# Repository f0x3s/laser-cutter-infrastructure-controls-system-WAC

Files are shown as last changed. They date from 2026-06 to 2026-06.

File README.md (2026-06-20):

# Laser Cutter Infrastructure Controls System
Relay-logic-based controls system to manage water-cooling, fume ventilation, and other auxiliary functions for the laser cutter &amp; digital fabrication space at the Walker Art Center.

This is intended as a maintenance resource for the existing system. Instructions for building a new system from scratch are currently outside of the scope of this repo.

> ### Additional Resources:
> * [arduino-industrial-AHU-status-indicator-WAC](https://github.com/f0x3s/arduino-industrial-AHU-status-indicator-WAC) — *Real-time feedback module for the __Paint Booth AHU__*
> * [arduino-industrial-AHU-interface-WAC](https://github.com/f0x3s/arduino-industrial-AHU-interface-WAC) — *Interface beween control module and __Paint Booth AHU__ 3-phase motor controller*

## Control Flow
<p align="center">
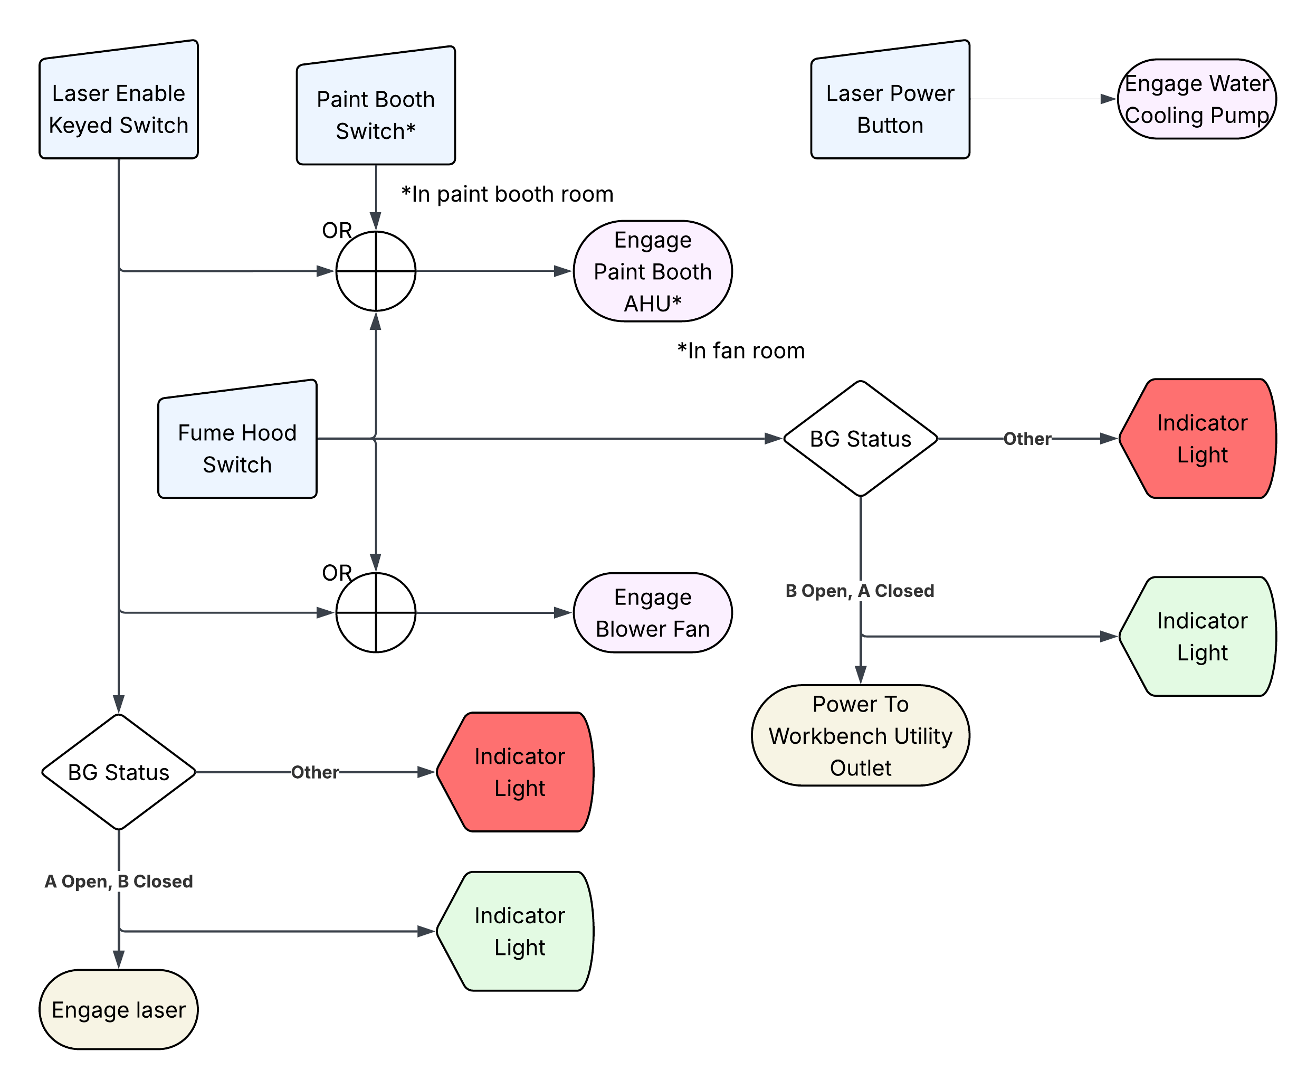
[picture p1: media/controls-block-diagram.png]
control flow block diagram
    
</p>

### Overview:
* **Water Cooling Pump** controlled with **Laser Power Button**, ensuring **Water Cooling Pump** is always engaged during **Laser** operation. 
* The **Paint Booth Air Handling Unit (AHU)** and local **Blower Fan** ensured to be always on while **Laser** or **Fume Hood** in use.
* Power to both a **Utility Outlet** at the fume hood workbench (to restrict access to fume-generating tools, like a soldering iron) and internal **Laser Tube** will be interrupted until correct orientation of **Blast Gates** is met, with **Indicator Lights** providing visual feedback.
* While not explicitly shown in this diagram, during operation of either the **Laser** or **Fume Hood** the switch in the **Paint Booth** is interrupted at the **Paint Booth AHU** motor controller in the **Fan Room** so that it may not be used to turn off **Paint Booth AHU**. See: ['arduino-industrial-AHU-interface-WAC'](https://github.com/f0x3s/arduino-industrial-AHU-interface-WAC)

## Air Handling Diagram
<p align="center">
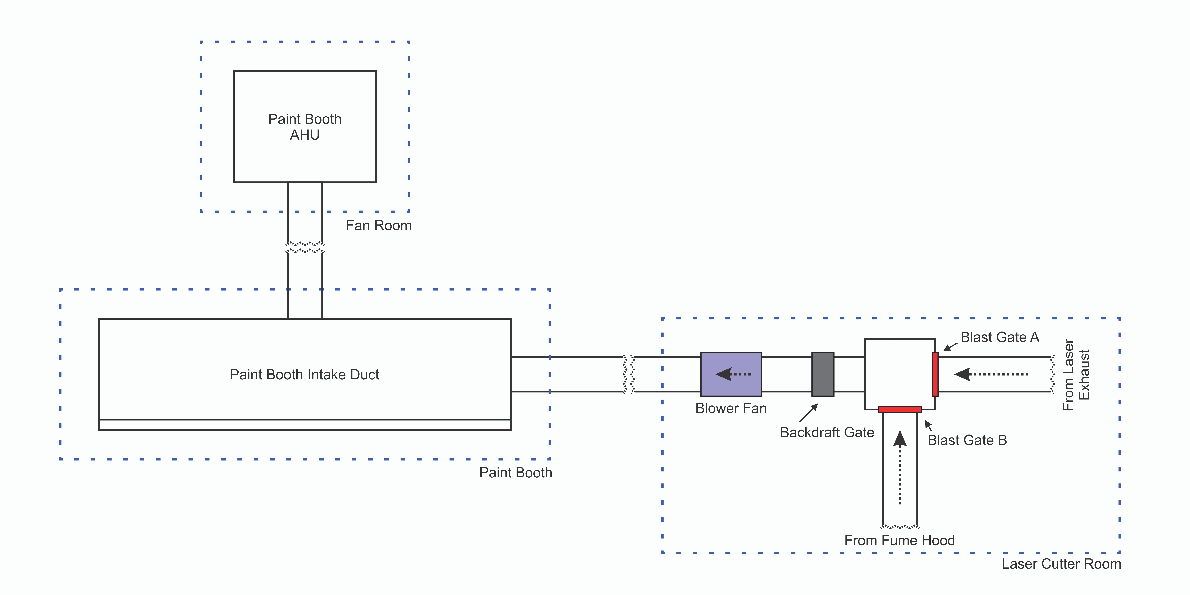
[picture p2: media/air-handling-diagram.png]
air handling diagram
    
</p>

#### Air Handling Specialty Parts
| qty | name | source |
| ---: | :---: | :---: |
| 2 | Long Ranger 4 in. Aluminum Blast Gate with Switch | [Penn State Industries](https://www.pennstateind.com/store/LRGATE.html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) |
| 1 | 6" Backdraft Damper | [Amazon](https://a.co/d/00BVJb6u) |

## Circuit Diagrams
#### Main Control Module
<p align="center">
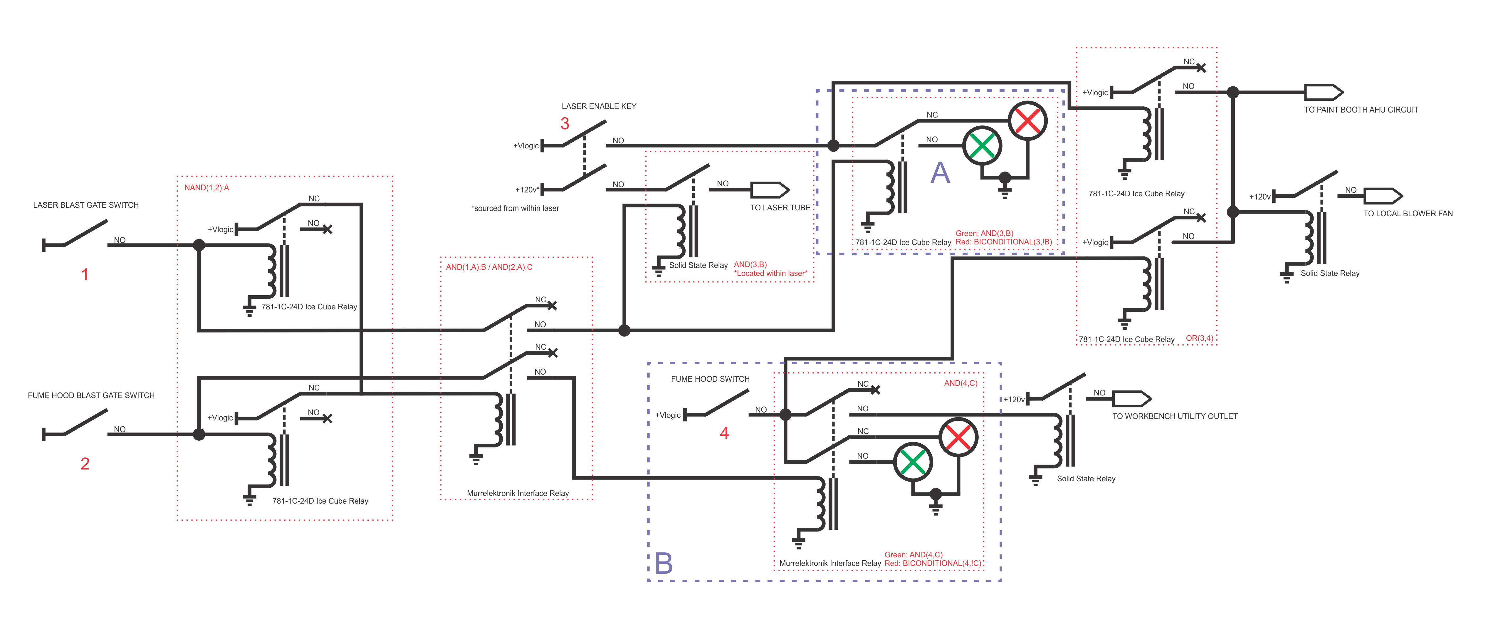
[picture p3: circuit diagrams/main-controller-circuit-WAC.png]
main control module electrical schematic
    
</p>

#### Indicator Light Modules
<p align="center">
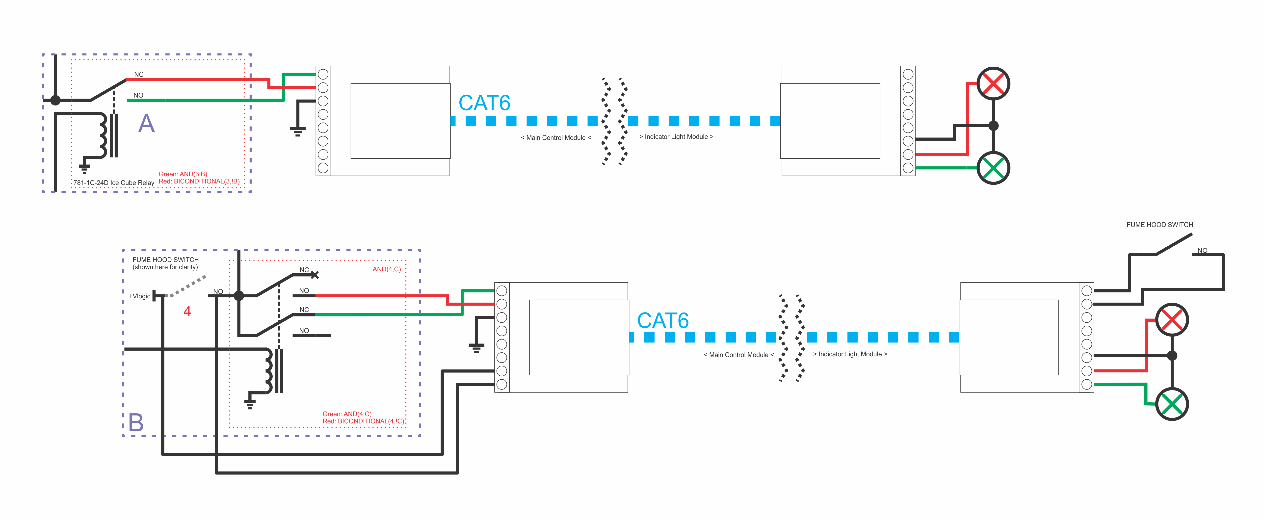
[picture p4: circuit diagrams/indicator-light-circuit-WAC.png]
indicator modules electrical schematic
    
</p>

#### Water Cooler Control Module
<p align="left">
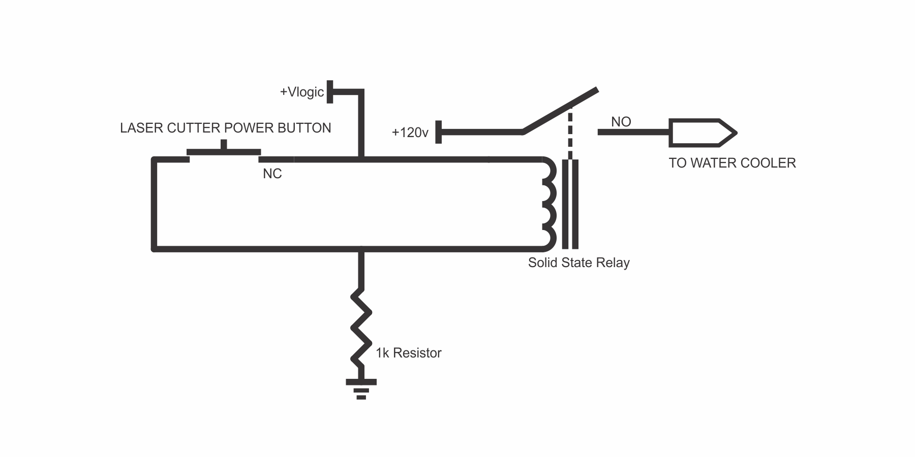
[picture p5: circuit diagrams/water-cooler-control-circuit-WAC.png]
water cooler control module electrical schematic
    
</p>

## Fabrication Files
All files to be cut from 0.25" acrylic unless otherwise specified.
> 📂 **[acrylic parts](acrylic%20parts)/**
> - 📁 [`source`](acrylic%20parts/source)/ — *Editable Corel Draw design files*
>   - 🗒️ [`indicator-light-enclosure-WAC.cdr`](acrylic%20parts/source/indicator-light-enclosure-WAC.cdr)
>   - 🗒️ [`relay-controller-main-enclosure-WAC.cdr`](acrylic%20parts/source/relay-controller-main-enclosure-WAC.cdr)
>   - 🗒️ [`relay-controller-water-cooler-enclosure.cdr`](acrylic%20parts/source/relay-controller-main-enclosure-WAC.cdr)
> - 🗒️ [`indicator-light-enclosure-WAC.dxf`](acrylic%20parts/indicator-light-enclosure-WAC.dxf) — *Enclosure for red/green blast gate status indicator lights*
> - 🗒️ [`relay-controller-main-enclosure-WAC.dxf`](acrylic%20parts/relay-controller-main-enclosure-WAC.dxf) — *Enclosure for primary relay logic module*
> - 🗒️ [`relay-controller-water-cooler-enclosure-WAC.dxf`](acrylic%20parts/relay-controller-water-cooler-enclosure-WAC.dxf) — *Enclosure for water cooler activation relay*

## Control Modules Parts Lists
_note: qty given as needed for assembly, without respect to package quantity from sources_
#### Indicator Light Module (per module)
_Requires 1x [`indicator-light-enclosure-WAC.dxf`](acrylic%20parts/indicator-light-enclosure-WAC.dxf)_
| qty | name | source |
| ---: | :---: | :---: |
| 10 | M3 nuts | [McMaster](https://www.mcmaster.com/90710A030/) |
| 8 | M3 x 16mm Button Head Machine Screw | [McMaster](https://www.mcmaster.com/92095A184/) |
| 2 | M3 x 35mm Button Head Machine Screw | [McMaster](https://www.mcmaster.com/92095A201/) |
| 2 | Nylon Standoff | [McMaster](https://www.mcmaster.com/90176A166/) |
| 2 |  3/16 x 1-3/4 concrete screw | [McMaster](https://www.mcmaster.com/90161A725/) |
| 1 |  RJ45 Socket Breakout | [Amazon](https://a.co/d/0dmWGGhN) |
| 1 |  Red & Green Indicator Light Pair | [Amazon](https://a.co/d/08HnO1Rn) |
| As Needed | Misc Hookup Wire | [Amazon](https://a.co/d/0hACIMdw) |

#### Main Control Module
_Requires 1x [`relay-controller-main-enclosure-WAC.dxf`](acrylic%20parts/relay-controller-main-enclosure-WAC.dxf)_
| qty | name | source |
| ---: | :---: | :---: |
| 24 | M3 nuts | [McMaster](https://www.mcmaster.com/90710A030/) |
| 20 | M3 x 16mm Button Head Machine Screw | [McMaster](https://www.mcmaster.com/92095A184/) |
| 4 | Nylon Standoff | [McMaster](https://www.mcmaster.com/90176A166/) |
| 4 |  3/16 x 1-3/4 concrete screw | [McMaster](https://www.mcmaster.com/90161A725/) |
| 4 |  1/2NPT Cable Grip | [Mouser](https://mou.sr/3KeBc74) |
| 4 |  1/2NPT Cable Grip Nut | [Mouser](https://mou.sr/3WWg4U7) |
| 2 | Murrelektronik Interface relay | [Automation Direct](https://www.automationdirect.com/adc/shopping/catalog/relays_-z-_timers/electro-mechanical_relays/52102) |
| 5 | 781-1C-24D Ice Cube Relay | [Automation Direct](https://www.automationdirect.com/adc/shopping/catalog/relays_-z-_timers/electro-mechanical_relays/781-1c-24d) |
| 5 | 781 Series Mounting Socket | [Automation Direct](https://www.automationdirect.com/adc/shopping/catalog/relays_-z-_timers/relay_-a-_timer_sockets/781-1c-skt) |
| 3 | 275mm DIN Rail | [Automation Direct](https://www.automationdirect.com/adc/shopping/catalog/wire_-a-_cable_management/din_rail/din_rail/dn-r35s-275-4) |
| 2 |  Solid State Relay | [Amazon](https://a.co/d/05lO5lyu) |
| 2 |  Aluminum SSR Heatsink | [Amazon](https://a.co/d/04LpVrm3) |
| 1 |  24v PSU (120w) | [Amazon](https://a.co/d/0cFTalkx) |
| 2 |  RJ45 Socket Breakout | [Amazon](https://a.co/d/0dmWGGhN) |
| 2 |  Lighted Edison Plug Set | [Amazon](https://a.co/d/048plgdh) |
| 1 |  IEC Panel-Mount Male Bulkhead | [Amazon](https://a.co/d/0hY4DzyT) |
| As Needed | Misc. Hookup Wire | [Amazon](https://a.co/d/0hACIMdw) |
| As Needed | Misc. Fork Connectors | [Amazon](https://a.co/d/01KCsaIr) |
| As Needed | Misc. Wago Connectors | [Amazon](https://a.co/d/03hsfrAt) |
| As Needed | 25a Bulk Extension Cord Wire | in-house |
| As Needed | 18ga 2-conductor speaker wire or equiv. | in-house |

#### Water Cooler Control Module
_Requires 1x [`relay-controller-water-cooler-enclosure-WAC.dxf`](acrylic%20parts/relay-controller-water-cooler-enclosure-WAC.dxf)_
| qty | name | source |
| ---: | :---: | :---: |
| 10 | M3 nuts | [McMaster](https://www.mcmaster.com/90710A030/) |
| 10 | M3 x 16mm Button Head Machine Screw | [McMaster](https://www.mcmaster.com/92095A184/) |
| 3 | Nylon Standoff | [McMaster](https://www.mcmaster.com/90176A166/) |
| 3 |  3/16 x 1-3/4 concrete screw | [McMaster](https://www.mcmaster.com/90161A725/) |
| 3 |  1/2NPT Cable Grip | [Mouser](https://mou.sr/3KeBc74) |
| 3 |  1/2NPT Cable Grip Nut | [Mouser](https://mou.sr/3WWg4U7) |
| 1 |  12v PSU (60w) | [Amazon](https://a.co/d/06WrZoo5) |
| 1 |  Solid State Relay | [Amazon](https://a.co/d/05lO5lyu) |
| 1 |  Aluminum SSR Heatsink (Large) | [Amazon](https://a.co/d/043KxMh4) |
| 2 |  Lighted Edison Plug Set | [Amazon](https://a.co/d/048plgdh) |
| 1 | .25w 1k Resistor | in-house |
| As Needed | Misc. Hookup Wire | [Amazon](https://a.co/d/0hACIMdw) |
| As Needed | Misc. Fork Connectors | [Amazon](https://a.co/d/01KCsaIr) |
| As Needed | Misc. Wago Connectors | [Amazon](https://a.co/d/03hsfrAt) |
| As Needed | 25a Bulk Extension Cord Wire | in-house |
| As Needed | 18ga 2-conductor speaker wire or equiv. | in-house |

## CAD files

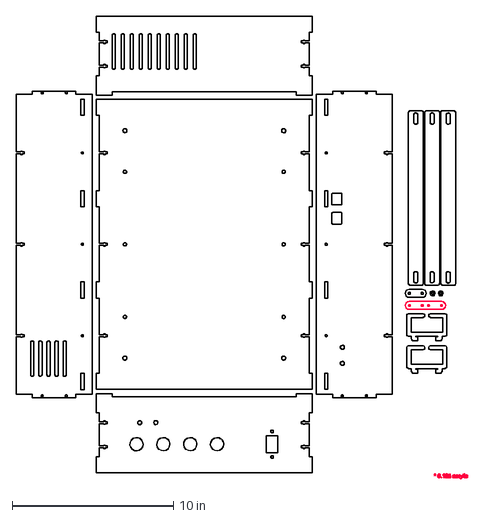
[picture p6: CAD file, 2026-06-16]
acrylic parts/relay-controller-main-enclosure-WAC.dxf
28.0 x 28.7 in

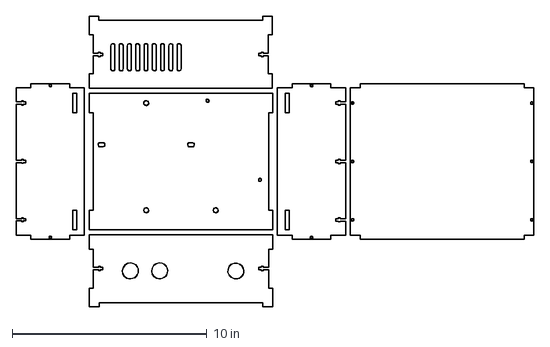
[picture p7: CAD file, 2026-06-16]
acrylic parts/relay-controller-water-cooler-enclosure-WAC.dxf
26.6 x 14.9 in

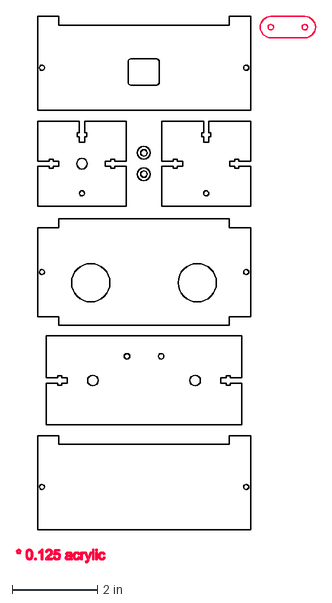
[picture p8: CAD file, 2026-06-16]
acrylic parts/indicator-light-enclosure-WAC.dxf
7.02 x 12.8 in
